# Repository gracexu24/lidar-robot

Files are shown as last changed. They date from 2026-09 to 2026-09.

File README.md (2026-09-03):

# Four-wheel ROS 2 LiDAR robot

ROS 2 Jazzy software for a Raspberry Pi 5, four STEP/DIR stepper drivers, an
MPU6050 IMU, and the Waveshare D500 kit (LDROBOT LD19 2D LiDAR). The package
supports physical hardware, keyboard driving, SLAM mapping, saved-map Nav2
navigation, and Gazebo Harmonic simulation.

1. [General project goal](#general-project-goal)
2. [File structure](#file-structure)
3. [Hardware list](#hardware-list)
4. [Project images](#project-images)
5. [Project features and decisions](#project-features-and-decisions)
6. [Issues and how we solved them](#issues-and-how-we-solved-them)
7. [Install](#install)
8. [Physical hardware setup and tests](#physical-hardware-setup-and-tests)
9. [Simulation](#simulation)
10. [Worklog](#worklog)

## General project goal

Build a small indoor/outdoor autonomous robot that can map a space, localize
in that map, and drive itself to a goal. The original product idea was a
cute food-delivery platform; later notes also listed outdoor jobs such as
trash collection, weed cutting, and GPS-guided travel. Those outdoor jobs
need extra sensors and tougher hardware, so this repository first proves the
core stack indoors:

- four-wheel skid-steer motion
- 2D LiDAR mapping with SLAM Toolbox
- saved-map navigation with Nav2
- optional IMU fusion for better short-term yaw
- a Gazebo simulation of the same ROS interfaces

The mechanical design is inspired by [TurtleBot3](https://www.turtlebot.com/turtlebot3/):
a simple mobile base, sensors on top, and replaceable skins rather than a
fixed enclosure. Early ideas included modular snap-fit tiles and
replaceable interior/exterior walls. The built robot uses a skateboard-style
3030 aluminum frame with 3D-printed motor mounts instead.

## File structure

```text
lidar-robot/
├── README.md
├── docs/
│   ├── cad/full-robot-assembly.stp  Fusion/STEP model of the built robot
│   └── images/                  Project photos and wiring figures
└── my_robot/                    ROS 2 Python package
    ├── package.xml              Package name, license, and dependencies
    ├── setup.py                 Installs nodes, launch, config, URDF, worlds
    ├── setup.cfg
    ├── resource/my_robot        ament package marker
    ├── config/
    │   ├── motors.yaml          GPIO pins and pulse-calibration numbers
    │   ├── mpu6050.yaml         I2C IMU driver settings
    │   ├── ekf.yaml             robot_localization fusion of wheels + IMU
    │   ├── slam.yaml            SLAM Toolbox mapping settings
    │   ├── nav2.yaml            AMCL, planners, costmaps, smoother
    │   └── gazebo_bridge.yaml   Gazebo ↔ ROS topic bridge
    ├── launch/
    │   ├── base.launch.py       Physical motors, LiDAR, optional IMU/EKF
    │   ├── mapping.launch.py    Physical base + SLAM Toolbox
    │   ├── navigation.launch.py Physical base + AMCL + Nav2
    │   ├── navigation_core.launch.py  Shared Nav2 servers
    │   ├── simulation.launch.py Gazebo robot, bridge, optional RViz
    │   ├── simulation_mapping.launch.py
    │   └── simulation_navigation.launch.py
    ├── my_robot/
    │   ├── base_controller.py   /cmd_vel → STEP rates + open-loop odom
    │   ├── stepper_hardware.py  Four GPIO pulse threads
    │   ├── mpu6050_driver.py    I2C IMU → /imu/data
    │   ├── lidar_reader.py      /scan connection diagnostics
    │   ├── manual_drive.py      Bounded front/back/left/right tests
    │   └── cmd_vel_watchdog.py  Simulation-only stale-command stop
    ├── urdf/robot.urdf          ROS frames and visual sizes
    ├── worlds/test_room.sdf     Gazebo room, robot, LiDAR, IMU
    ├── rviz/robot.rviz          Shared RViz layout
    └── test/                    Lint and mocked GPIO timing tests
```

How the main files work together:

- `base_controller.py` converts `/cmd_vel` (`linear.x`, `angular.z`) into left
  and right step rates, ramps those rates, stops if commands go stale, and
  publishes open-loop `/wheel/odom`.
- `stepper_hardware.py` owns the four STEP/DIR/RESET/SLEEP pins.
- `mpu6050_driver.py` publishes accelerometer and gyro data on `/imu/data`.
- `lidar_reader.py` reports closest-range and stale-scan warnings.
- `manual_drive.py` is the `ros2 run my_robot drive ...` test helper.
- `base.launch.py` starts the physical robot. Mapping and navigation launches
  include it, then add SLAM Toolbox or AMCL + Nav2.
- `navigation_core.launch.py` starts the shared Nav2 servers and remaps
  Jazzy's `/cmd_vel_smoothed` to `/cmd_vel`.
- Simulation launches use Gazebo instead of GPIO. They still speak
  `/cmd_vel`, `/odom`, `/scan`, `/imu/data`, and TF.

## Hardware list

CAD model: [docs/cad/full-robot-assembly.stp](docs/cad/full-robot-assembly.stp)
(Fusion 360 STEP export of the full robot assembly; open in Fusion 360, FreeCAD, or another STEP viewer.)

| Item | What we used | Notes |
| --- | --- | --- |
| Computer | Raspberry Pi 5 | Ubuntu 24.04 + ROS 2 Jazzy. An active fan was added after heat issues. |
| LiDAR | Waveshare D500 kit (LDROBOT LD19) | USB serial. Wiki: [D500 LiDAR Kit](https://www.waveshare.com/wiki/D500_LiDAR_Kit). |
| IMU | MPU6050 | I2C, default address `0x68` when AD0 is low. |
| Motors | 4 bipolar steppers, 1.8° / 200 steps per revolution | Early pick: [Olimex SM-42HB34F08AB](https://www.digikey.com/en/products/detail/olimex-ltd/SM-42HB34F08AB/21662229), 12 V, 1.33 A. Direct drive, no gearbox. |
| Drivers | 4 A4988 / A5984-style STEP/DIR boards | Current limit set near 1 A (`Vref` about 0.8 V on the boards we used). MS pins left unconnected, so the drivers stay in full-step mode. |
| Motor power | 12 V rechargeable pack, about 5.8 Ah | Sized for roughly an hour of four-motor current with margin. A 1 A wall supply was not enough for all four motors. |
| Pi power | Separate USB power bank / phone battery | Do not power motors from the Pi 5 V or 3.3 V pins. |
| Wheels | 4 in / about 10 cm diameter | Loaded radius in the URDF is 0.049 m. |
| Frame | 3030 aluminum extrusion | Replaced a planned one-piece carbon-fiber print. |
| Mounts | 3D-printed motor mounts and axle parts | Early notes used U-joints between 3 mm motor shafts and larger wheel shafts. |
| Caps | 100 µF electrolytic across each driver `VMOT`/`GND` | Limits supply spikes when stepping. |

Motor wiring color convention used during bring-up:

- `1A` black, `1B` green, `2A` red, `2B` blue

Split electrical system from the side-layout drawing: the phone battery feeds
the Pi, the 12 V pack feeds the motor drivers, and both grounds meet at the
drivers.

Default GPIO order is left-front, left-rear, right-front, right-rear (BCM
numbers, not physical header pins):

| Signal | LF | LR | RF | RR |
| --- | ---: | ---: | ---: | ---: |
| STEP | 14 | 23 | 17 | 5 |
| DIR | 15 | 24 | 27 | 6 |
| RESET | 4 | 25 | 22 | 26 |
| SLEEP | 12 | 7 | 16 | 1 |

`direction_inverted`: `[true, true, false, false]`

Change these in `my_robot/config/motors.yaml` if the physical wiring changes.

## Project images

These figures come from the project notebook. Photos of the assembled robot
are not in this repository yet.

Early modular-tile chassis sketch. This layout was later dropped for a
single skateboard-style frame.

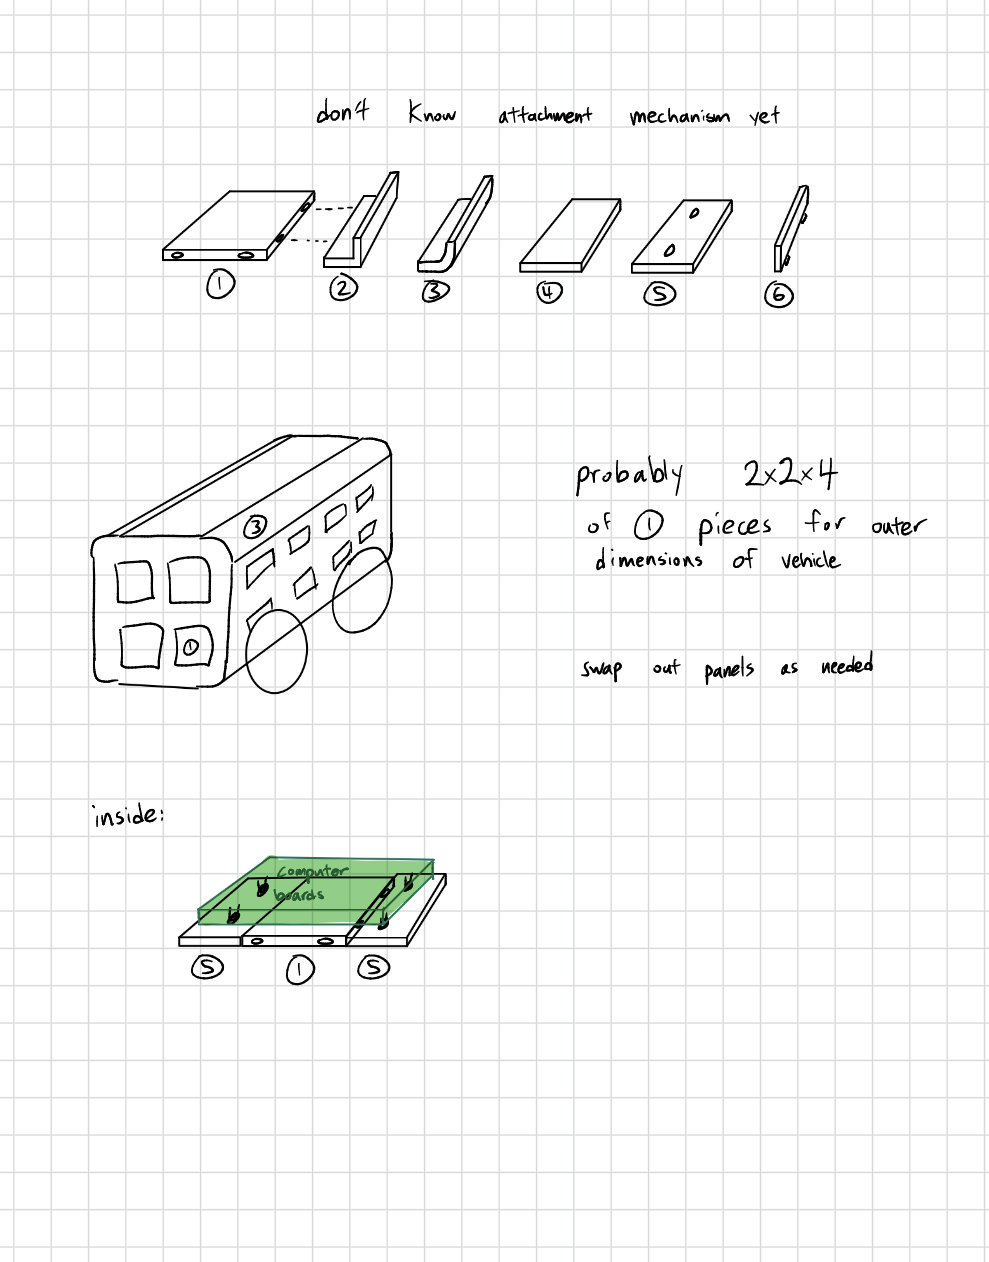
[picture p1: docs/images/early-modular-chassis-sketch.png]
Early modular chassis sketch


Motor, 4 in wheel, and U-joint notes, including shaft-strength estimates.

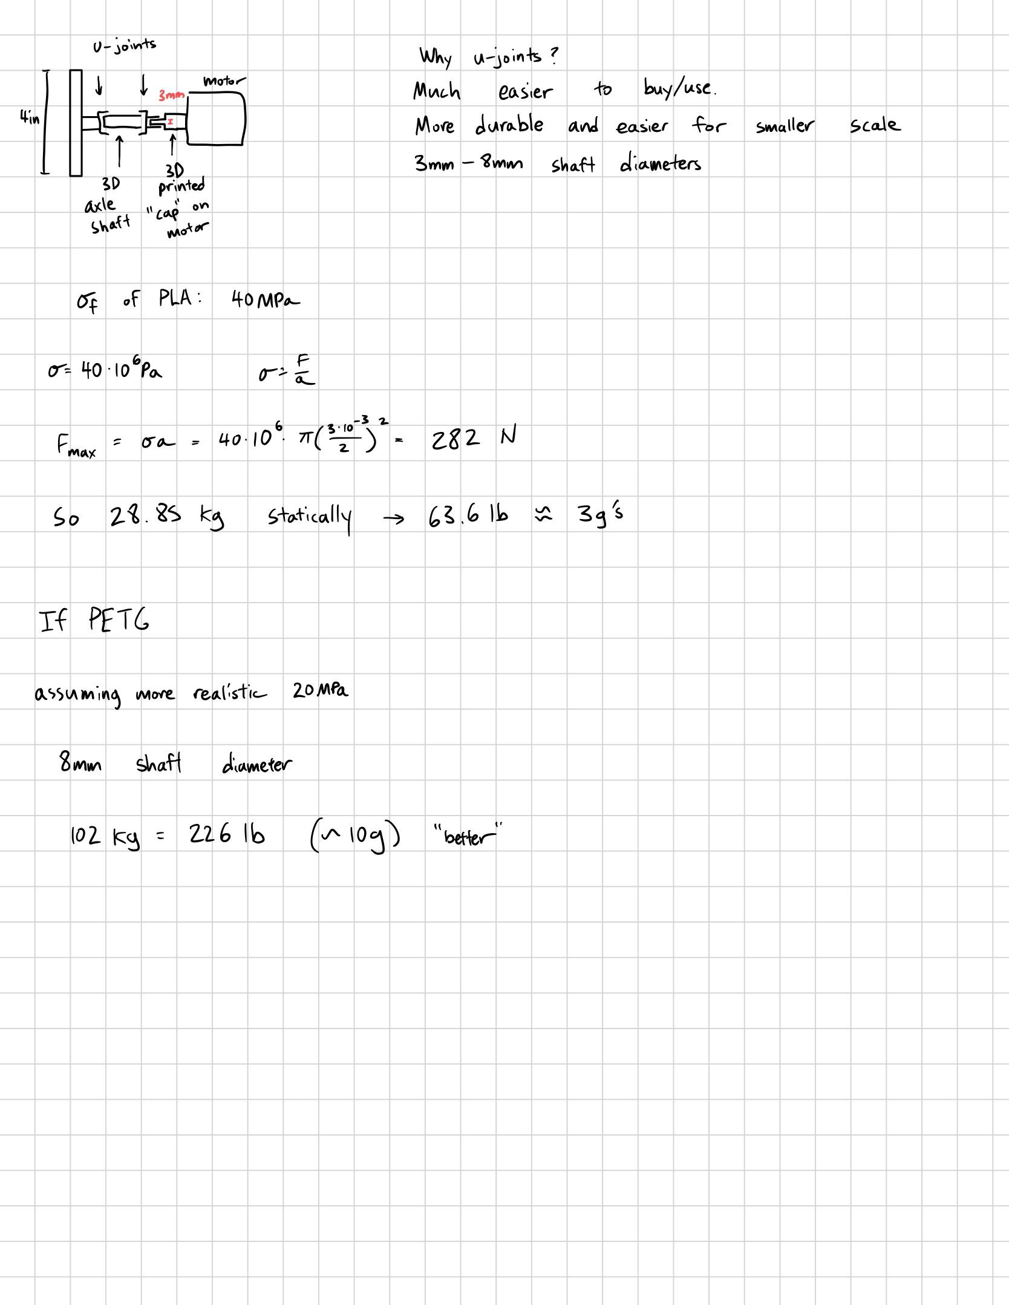
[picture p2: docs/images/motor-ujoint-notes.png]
Motor and U-joint notes


First 2D side-view layout. Red is signal, green is power. The LiDAR sits at
the front, the Pi and its battery in the middle, and the 12 V pack at the
rear.

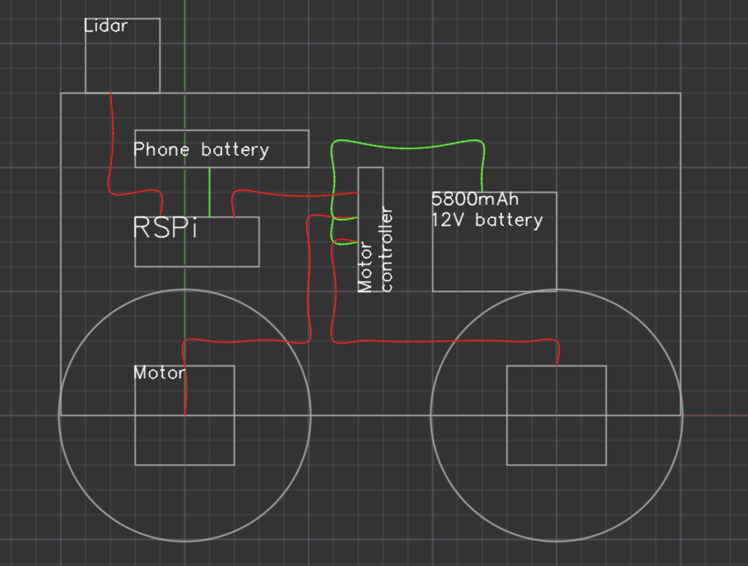
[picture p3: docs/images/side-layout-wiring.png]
Side layout and power/signal routing


A5984-style driver wiring used as the electrical reference: STEP/DIR from the
Pi, 100 µF on motor power, and a shared logic ground.

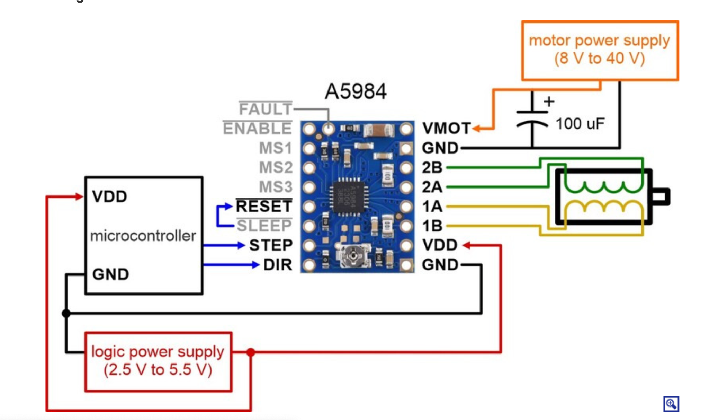
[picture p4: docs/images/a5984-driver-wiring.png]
A5984 stepper-driver wiring


## Project features and decisions

### Features that are in the repo

- Keyboard and bounded command-line driving (`front`, `back`, `left`, `right`)
- Open-loop wheel odometry from commanded stepper pulses
- D500 LiDAR scans on `/scan`
- Optional MPU6050 + EKF fusion
- Online SLAM mapping and map saving
- Saved-map Nav2 navigation
- Gazebo Harmonic simulation with the same high-level topics
- Collision-aware local planning with DWB; conservative speed limits for the Pi

### Mechanical decisions

- Four wheels instead of two, to keep the platform simple and stable. Notes
  assumed about 9 kg, 0.5 m/s, and 0.5 m/s² while sizing torque.
- Snap-fit 3 in tiles were dropped. 3D-printed latches were expected to creak,
  fit poorly, and be weak because printed plastic is not isotropic. Injection
  molding would have made that idea more realistic.
- A skateboard layout won: one strong flat frame, electronics on top, and a
  non-structural skin later.
- A single Markforged carbon-fiber frame was dropped after the print was
  estimated at more than 19 hours. 3030 extrusion plus printed motor mounts
  is easier to assemble and modify.
- Suspension was designed as a later add-on, not a first-version requirement.
- Camera support was planned and is not implemented yet.

### Electrical and software decisions

- Drive the steppers from the Pi GPIO with STEP/DIR pulses, not from an
  Arduino motor shield. One pulse is one full step (1.8°). Speed is the
  pulse frequency, not a PWM duty cycle.
- Leave driver MS pins unconnected. The A4988/A5984 internal pull-downs keep
  the chips in full-step mode, so the electrical step count is locked at 200
  pulses per motor revolution.
- Calibrate motion with `left_steps_per_meter`, `right_steps_per_meter`,
  `left_turn_steps_per_radian`, and `right_turn_steps_per_radian` instead of
  hiding error inside `wheel_radius` / `wheel_separation`.
- Use separate left and right turn coefficients because skid-steer left and
  right turns were not equal on the real floor.
- Keep IMU fusion optional. The MPU6050 has no magnetometer, so it helps
  short-term yaw rate and cannot provide absolute heading.
- Do not start Nav2 during mapping unless asked. The Pi was dropping scans
  and transforms when SLAM and Nav2 ran together.
- Build simulation around the same `/cmd_vel`, `/odom`, `/scan`, `/imu/data`,
  and TF contracts so mapping and Nav2 can be practiced without GPIO.

### Frames

- `base_footprint`: ground-level center used by Nav2 for planar collision
- `base_link`: chassis frame above the floor, normally at axle height
- `base_laser`: LiDAR scan origin; angle 0 is +X, forward
- `imu_link`: MPU6050 chip frame

ROS axes are +X forward, +Y left, and +Z up.

## Issues and how we solved them

| Problem | What we saw | Fix |
| --- | --- | --- |
| Wrong Ubuntu image | Pi stayed on a red light after a reflash | Ubuntu **24.04** is required for ROS 2 Jazzy binaries. Raspberry Pi OS is not a supported Jazzy platform. |
| Wall supply starved the motors | Four motors buzzed or refused to start together | Use the 12 V battery. A 1 A wall supply cannot feed four 1 A-class steppers. |
| Random wheels dead, stuck on, or buzzing | Motor 2 always on; motor 3 buzzed and did not turn | Rewired STEP/DIR/RESET/SLEEP, stopped RESET from being shorted, split shared jumper wires, and learned that RESET must stay high or STEP is ignored. |
| ENABLE vs RESET vs SLEEP confusion | Sleep seemed to work; RESET did not | RESET home-states the translator and ignores STEP until it is high. SLEEP cuts power and needs about 1 ms after wake before the next step. The code pulses RESET at start, holds it high, and uses SLEEP when a wheel is stopped. |
| GPIO pin conflicts | IMU needed I2C; some motor pins sit on UART/SPI | Moved motor pins to the table above. GPIO14/15 need the serial console off. GPIO7 is SPI CE1. GPIO1 is often reserved for HAT ID. |
| Vendor LiDAR package failed to build | Missing `pthread` in the given LDROBOT code | Build `ldlidar_stl_ros2` after ROS itself is installed, and keep the vendor package next to `my_robot` in `src`. |
| Printed parts did not fit | Assembly stopped | Measured the real robot, reprinted mounts, and put those sizes in the URDF. |
| Pi “battery” was not a battery | Logic power dropped | Separate USB power bank for the Pi; 12 V pack only for motors. |
| Distance math was wrong | 200 pulses turned the wheel once, but travel was about half the theoretical distance | Stopped treating `wheel_radius` as a software knob. Calibrate `steps_per_meter` from measured travel. Floor tests later landed near 707 / 699 steps/m. |
| Left and right turns disagreed | Left ~40° when 90° was requested; right needed a much larger coefficient | Separate `left_turn_steps_per_radian` and `right_turn_steps_per_radian`. Also check sagging hubs and drag before trusting the numbers. |
| Wheels sagged or fell off | Turns scrubbed; hubs walked off the shafts | Tape or glue hubs for tests; prefer moving arcs (`u`/`o`) over in-place `j`/`l` turns. |
| Motors stalled after raising speed | Buzz, missed steps, or no rotation | Raise `max_step_rate` and `max_step_acceleration` only after raised-wheel then floor tests. Current values are 500 steps/s and 300 steps/s²; older conservative limits were 75 and 100. |
| Pulse timing looked faster than commanded | 50 Hz controller woke every pulse thread even when the rate was unchanged | `set_rate()` now signals a thread only when the rate changes. A unit test covers that. |
| IMU did not start | `/imu/data` missing; mapping still fuzzy | Add the user to the `i2c` group, keep the robot still for gyro bias, and confirm `i2cdetect` shows `68`. One mapping run used a bad IMU init and only three wheels. |
| SLAM maps were fuzzy / scans dropped | Buffer warnings while printing debug | Turn `debug_logging` off while mapping. Do not start Nav2 during mapping unless needed. |
| Nav2 planned but the robot sat still | Controller rejected the path; wrong velocity topic | Jazzy smoother output is `/cmd_vel_smoothed`, not Humble's `/smoothed_cmd_vel`. `navigation_core.launch.py` remaps that to `/cmd_vel`. |
| Mapping plus Nav2 overloaded the Pi | Transform delays, `follow_path` timeouts | Mapping defaults to SLAM only. `bt_navigator` timeouts and AMCL transform tolerances were increased for the Pi. |
| Gazebo would not yaw | `/odom` said it turned; the body did not | SDF wheel friction was given a small lateral slip. That change is simulation-only. |
| Gazebo kept the last speed forever | Robot rolled after teleop stopped | `cmd_vel_watchdog.py` zeros velocity after 0.6 s. The physical controller already has a 0.5 s watchdog. |

Open limitations we did not fully remove:

- Odometry counts pulses sent to the drivers. It cannot see skipped steps or
  slip.
- Python on Linux is not hard real-time GPIO. Faster, cleaner motion would
  need a microcontroller generating STEP pulses.
- Outdoor GPS, camera, and suspension are still future work.
- Dependable navigation still wants wheel encoders.

## Install

Use 64-bit Ubuntu 24.04 and ROS 2 Jazzy.

Labels used below:

- **Once per machine**: run after a new OS install.
- **Pi only**: skip on a desktop that will only run Gazebo.
- **Desktop only**: skip on the Raspberry Pi.
- **Every new terminal**: ROS does not keep `source` across terminals.
- **After code changes**: launch, config, URDF, or Python edits.

### 1. ROS packages — once per machine

```bash
sudo apt update
sudo apt install -y ros-jazzy-desktop ros-jazzy-navigation2 \
  ros-jazzy-nav2-bringup ros-jazzy-slam-toolbox \
  ros-jazzy-robot-localization ros-jazzy-teleop-twist-keyboard \
  python3-rosdep
```

### 2. Raspberry Pi hardware packages — Pi only, once

```bash
sudo apt install -y python3-gpiozero python3-lgpio python3-smbus2 i2c-tools
```

### 3. Gazebo packages — desktop only, once

```bash
sudo apt install -y ros-jazzy-ros-gz
```

### 4. rosdep — once per machine

If it says rosdep is already initialized, continue with `rosdep update`.

```bash
sudo rosdep init
rosdep update
```

### 5. Workspace and source — once per machine

```bash
mkdir -p ~/ros2_ws/src
cd ~/ros2_ws/src
git clone https://github.com/gracexu24/lidar-robot.git
git clone https://github.com/ldrobotSensorTeam/ldlidar_stl_ros2.git
```

Later updates on the Pi are `git pull` inside this repo, then rebuild.

### 6. Dependencies and first build — once, then after new dependencies

```bash
cd ~/ros2_ws
source /opt/ros/jazzy/setup.bash
rosdep install --from-paths src --ignore-src -r -y
colcon build --symlink-install
source ~/ros2_ws/install/setup.bash
```

`source /opt/ros/jazzy/setup.bash` must run before `rosdep install` and
`colcon build`. The vendor LiDAR package expects ROS to already be installed.

### 7. Every new terminal

```bash
source /opt/ros/jazzy/setup.bash
source ~/ros2_ws/install/setup.bash
```

Confirm the package is visible:

```bash
ros2 pkg prefix my_robot
```

### 8. After changing package files

```bash
cd ~/ros2_ws
source /opt/ros/jazzy/setup.bash
colcon build --symlink-install --packages-select my_robot
source ~/ros2_ws/install/setup.bash
```

### 9. Package tests — optional, after code changes

```bash
cd ~/ros2_ws
source /opt/ros/jazzy/setup.bash
colcon test --packages-select my_robot
colcon test-result --verbose
```

The tests include lint checks and mocked motor sleep/reset/timing checks.
They do not move hardware.

### 10. One-time Pi permissions

Serial (LiDAR). Log out or reboot after the group change:

```bash
sudo usermod -aG dialout "$USER"
groups
```

I2C (IMU):

```bash
sudo usermod -aG i2c "$USER"
```

Enable I2C in `/boot/firmware/config.txt` if `/dev/i2c-1` is missing
(`dtparam=i2c_arm=on`), then reboot.

## Physical hardware setup and tests

Save work before unplugging the Pi. Unplug motor power before moving wires.

The Raspberry Pi GPIO pins must connect to stepper-driver logic inputs, not
directly to motors. Use one correctly sized driver per motor, an external
motor power supply, current limiting, and a common ground between the
supply, drivers, and Pi. Never power motors from a Pi 5 V or 3.3 V pin.

Raise the wheels for initial tests and keep a physical emergency motor-power
disconnect within reach.

GPIO7 is SPI CE1 and is unavailable while SPI is enabled. Either choose
another GPIO and move that SLEEP wire, or disable SPI in
`/boot/firmware/config.txt` if no other device uses it. GPIO14 and GPIO15
are UART pins, so the serial console must not use them.

The code assumes active-low RESET and SLEEP, as used by A4988-style drivers.
It pulses RESET during initialization, leaves RESET high, and pulls SLEEP
low when a wheel is stopped. Verify these levels against the exact driver
datasheet.

Driver current limit used on this robot: about 1 A, `Vref` about 0.8 V.
Set that on each board before long runs. See
[this current-limit walkthrough](https://youtu.be/89BHS9hfSUk?si=mE6hSFoFv12Aey9d)
if the pot location is unclear.

### Shared ROS commands

These commands are used by both the physical robot and simulation.

#### Keyboard control

A robot or simulation launch must already be running. In a separate sourced
terminal:

```bash
ros2 run teleop_twist_keyboard teleop_twist_keyboard \
  --ros-args --remap cmd_vel:=/cmd_vel
```

Useful keys:

- `i`: forward
- `,`: reverse
- `j`: turn left
- `l`: turn right
- `u` and `o`: move forward in left and right arcs
- `k`: stop
- `q` and `z`: increase and decrease all speeds
- `w` and `x`: increase and decrease linear speed
- `e` and `c`: increase and decrease angular speed
- `Ctrl+C`: exit

Prefer moving arcs instead of stationary turns when possible. Keyboard `u`
and `o` combine forward motion with turning, reducing tire scrub and stress
on the wheel hubs.

The physical motor controller has a 0.5-second watchdog, so hold or repeat a
movement key. Press `k` before leaving the keyboard terminal.

#### RViz setup

Simulation launches already start RViz with `rviz/robot.rviz`. That config
uses Fixed Frame `map` and adds the saved map, costmaps, laser scan, robot
model, TF, and the Navigation 2 panel.

Start RViz manually when a launch does not start it:

```bash
rviz2 -d "$(ros2 pkg prefix my_robot)/share/my_robot/rviz/robot.rviz"
```

For basic driving without SLAM or Nav2, use `odom` as the Fixed Frame. For
mapping and navigation, keep `map`. If a Map display shows nothing, set its
topic durability to Transient Local; `/map` is published once, not
continuously.

When using SSH, run RViz on another ROS 2 Jazzy computer on the same ROS
domain, use X11 forwarding, or use Foxglove.

#### Save the active map

Keep the mapping launch running. In another sourced terminal, choose a
filename without an extension and run:

```bash
MAP_NAME=${MAP_NAME:-$HOME/maps/home}
mkdir -p "$(dirname "$MAP_NAME")"
ros2 run nav2_map_server map_saver_cli -f "$MAP_NAME"
ls -l "$MAP_NAME.yaml" "$MAP_NAME.pgm"
```

Both the YAML and image file must exist before stopping mapping. Change
`MAP_NAME` to `$HOME/maps/sim_home` when saving a simulation map.

### Configure LiDAR serial access

Connect the D500 USB adapter and find its stable path:

```bash
ls -l /dev/serial/by-id/
```

Use the `/dev/serial/by-id/...` path in launch commands. `/dev/ttyUSB0` is
used below for brevity. Do not use broad `chmod 666` or `chmod 777`
permissions as a permanent solution.

### Motor connection test

Raise all wheels and start only the physical motor controller:

```bash
ros2 launch my_robot base.launch.py \
  start_motors:=true start_lidar:=false use_imu:=false \
  debug_logging:=true
```

In another sourced terminal, issue one bounded command at a time:

```bash
ros2 run my_robot drive front --duration 1 --speed 0.05
ros2 run my_robot drive back --duration 1 --speed 0.05
ros2 run my_robot drive left --duration 1 --turn-speed 0.4
ros2 run my_robot drive right --duration 1 --turn-speed 0.4
```

The debug output reports GPIO initialization, target and actual pulse rates,
pulse counts, wake/sleep changes, and watchdog stops. Pulse counts prove
that software generated pulses; without encoders they do not prove that a
motor physically moved.

### Keyboard-only motor movement

Raise-test all wheels first. Terminal 1 starts the motor controller without
the LiDAR or IMU:

```bash
ros2 launch my_robot base.launch.py \
  start_motors:=true start_lidar:=false use_imu:=false \
  debug_logging:=true
```

In Terminal 2, run the command under **Keyboard control**.

### IMU connection test

The I2C scan must show address `68`, or `69` when AD0 is tied high:

```bash
ls -l /dev/i2c-1
i2cdetect -y 1
```

Keep the robot still and start only the MPU6050 node:

```bash
ros2 run my_robot mpu6050_driver --ros-args \
  --params-file "$(ros2 pkg prefix my_robot)/share/my_robot/config/mpu6050.yaml" \
  -p debug_logging:=true
```

In another sourced terminal:

```bash
timeout 5s ros2 topic hz /imu/data
ros2 topic echo /imu/data --once
```

The data rate should be near 50 Hz. At rest, angular velocity should be near
zero and total acceleration near 9.8 m/s². Keep the robot still for the
first approximately 2.5 seconds while gyro bias is measured.

### LiDAR connection test

Start only the LiDAR:

```bash
ros2 launch my_robot base.launch.py \
  start_motors:=false start_lidar:=true use_imu:=false \
  lidar_port:=/dev/ttyUSB0 debug_logging:=true
```

In another sourced terminal:

```bash
ros2 topic info /scan --verbose
timeout 5s ros2 topic hz /scan
ros2 topic echo /scan --once
```

The expected rate is about 10 Hz. A few `nan` values are normal when no
valid reflection is returned. Debug output reports the closest valid
distance and warns when the scan stream is missing or stale.

In RViz, set Fixed Frame to `base_laser`, add `/scan` as a LaserScan, and
move an object in front of the sensor.

### Values to measure and tune

Use metres, radians, seconds, kilograms, and SI-derived units throughout the
configuration. Define `base_link` at the robot's rotation center: halfway
between the front and rear axles, on the left-to-right centerline, at axle
height. `base_footprint` is the point directly below it on the floor.

Record these physical measurements before calibration:

- loaded wheel radius: axle center to floor with the robot at operating weight
- left-to-right wheel separation: center of left tread to center of right tread
- wheelbase: front axle center to rear axle center
- overall body length, width, and height, including parts that can collide
- front, rear, left, and right extents measured from `base_link`
- floor-to-axle height
- robot total mass and approximate center of mass, if Gazebo should be realistic
- LiDAR sensing-center position and orientation relative to `base_link`
- IMU chip-center position and board orientation relative to `base_link`

Enter or tune the following values.

#### `my_robot/config/motors.yaml`

- `step_pins`, `dir_pins`, `reset_pins`, `sleep_pins`: actual BCM GPIO wiring
  in LF, LR, RF, RR order
- `direction_inverted`: one Boolean per wheel; tune with the wheels raised
- `left_steps_per_meter`: calibrated average left-side pulses per metre
- `right_steps_per_meter`: calibrated average right-side pulses per metre
- `left_turn_steps_per_radian`: average pulses for one radian of left rotation
- `right_turn_steps_per_radian`: average pulses for one radian of right rotation
- `max_step_rate`: highest reliable pulse rate in steps/s without missed steps
- `max_step_acceleration`: highest reliable ramp in steps/s² without stalling
- `command_timeout`: safety stop delay in seconds; normally leave at 0.5

The current controller sends one rate to both left wheels and another to both
right wheels. Physical wheel radius and separation remain real dimensions in
the URDF and Gazebo model; motor conversion uses the directly measured pulse
coefficients above.

#### `my_robot/urdf/robot.urdf`

- body box `size`: measured length, width, and height in metres
- body visual `origin xyz`: body-box center relative to `base_link`
- `base_joint` Z: floor-to-`base_link` height, normally the loaded wheel radius
- `laser_joint xyz`: `base_link` to the LiDAR rotating/sensing center in metres
- `laser_joint rpy`: LiDAR roll, pitch, and yaw in radians
- `imu_joint xyz`: `base_link` to the center of the MPU6050 chip in metres
- `imu_joint rpy`: rotation needed to align IMU axes with the ROS robot axes

Common angles are 90° = 1.5708 rad and 180° = 3.1416 rad. Sensor positions
must be measured to the sensing center, not to an enclosure edge.

#### `my_robot/config/mpu6050.yaml`

- `i2c_bus`: bus reported by the system, normally `1`
- `i2c_address`: `0x68` or `0x69`, as reported by `i2cdetect`
- `gyro_stddev`: stationary angular-velocity standard deviation in rad/s
- `accel_stddev`: stationary linear-acceleration standard deviation in m/s²
- `publish_rate`: measured sustainable data rate; normally leave at 50 Hz
- `calibration_samples`: increase for a steadier bias estimate if startup time
  is acceptable; keep the robot still for all samples

The `frame_id` must remain the same as the URDF IMU link unless both are
renamed together.

#### `my_robot/config/nav2.yaml`

- robot collision shape in both local and global costmaps: use either
  `robot_radius` or a `footprint`, but not both
- `robot_radius`: center to the furthest collidable point plus a small margin
- rectangular `footprint`: ordered `[x, y]` corners measured from
  `base_footprint`, including wheels, bumpers, and sensor mounts
- `footprint_padding`: additional collision margin, typically 0.01–0.03 m
- `inflation_radius`: desired navigation clearance around obstacles
- `obstacle_max_range`: maximum range at which LiDAR returns are reliably marked
- `raytrace_max_range`: reliable clearing range, slightly greater than the
  obstacle range but not beyond useful LiDAR data
- `max_vel_x` and `max_vel_theta`: safe measured linear and angular speeds
- `acc_lim_x`, `decel_lim_x`, `acc_lim_theta`, `decel_lim_theta`: acceleration
  limits that do not cause skipped steps or tipping
- velocity-smoother limits: keep them consistent with the controller limits
- goal tolerances and progress timeout: tune only after odometry is calibrated

For a centered rectangular robot, the minimum enclosing radius is:

```text
robot_radius = sqrt((length / 2)² + (width / 2)²) + safety margin
```

A more accurate asymmetric footprint uses the measured extents:

```yaml
footprint: "[[front, left], [front, -right], [-rear, -right], [-rear, left]]"
footprint_padding: 0.02
```

Replace `front`, `rear`, `left`, and `right` with distances in metres, and
use the same footprint in both costmaps.

#### `my_robot/config/slam.yaml`

- `max_laser_range`: maximum distance that produces dependable measurements,
  not merely the advertised maximum
- `resolution`: map cell size in metres; 0.05 m is a normal starting point
- minimum travel distance and heading: tune only if maps update too often or
  fail to update during deliberate motion

#### `my_robot/worlds/test_room.sdf`

These values affect only Gazebo. Copy calibrated real dimensions when the
simulation should match the physical robot:

- body collision and visual length, width, height, and center
- wheel X/Y positions, radius, width, mass, and inertia
- `wheel_separation` and `wheel_radius` in the DiffDrive plugin
- robot mass, center of mass, and inertia estimates
- simulated LiDAR and IMU poses
- LiDAR minimum/maximum range, sample count, and update rate

The URDF and SDF are separate models; changing one does not update the other.
The current SDF is synchronized to the measured 0.24 × 0.16 × 0.04 m body,
0.049 m wheel radius, 0.03 m wheel width, 0.165 m wheel separation, and
current LiDAR and IMU transforms. It still assumes a 0.22 m wheelbase, 8 kg
base mass, and 0.3 kg per wheel until those values are measured.

### Calibration procedure

1. Verify all GPIO assignments against the physical wiring.
2. Raise the wheels and tune `direction_inverted`.
3. Calculate initial steps/metre, then measure left and right travel.
4. Find conservative step-rate and acceleration limits.
5. Calibrate straight distance, then steps/radian for turns.
6. Enter body and sensor measurements in the URDF and Nav2 costmaps.
7. Validate IMU axes and noise values.
8. Copy the final geometry into the Gazebo SDF if simulation should match.

Calculate an initial translation estimate from the electrical and mechanical
configuration:

```text
steps_per_wheel_revolution =
    motor full steps/revolution × microstep setting × gearbox ratio

initial steps_per_meter =
    steps_per_wheel_revolution ÷ (2π × loaded wheel radius)
```

The A4988 MS1, MS2, and MS3 inputs have internal pull-down resistors. When
all three pins are unconnected, the driver uses full-step mode. Therefore a
1.8° motor requires 200 STEP pulses per motor revolution. With direct drive,
that is also 200 pulses per wheel revolution. A gearbox would multiply this
value by its reduction ratio.

Use this result as the initial value for both `left_steps_per_meter` and
`right_steps_per_meter`. The controller changes STEP frequency to change
speed:

```text
left frequency = requested translation × left_steps_per_meter
                 - requested rotation × direction_turn_steps_per_radian

right frequency = requested translation × right_steps_per_meter
                  + requested rotation × direction_turn_steps_per_radian
```

With a 0.049 m wheel radius and 200 steps/revolution, the theoretical
starting value is about 650 steps/m. Use the configured left and right
values when calculating the requested pulse rates.

#### Correct movement directions

Raise all wheels and run the short front, back, left, and right commands
from the motor test:

- `front`: all four wheel contact surfaces must move toward the robot's rear,
  which propels the robot forward when placed on the floor
- `back`: all four wheels must reverse
- `left`: left wheels reverse while right wheels move forward
- `right`: right wheels reverse while left wheels move forward

If one wheel is reversed, toggle only its matching `direction_inverted`
entry. If an entire side behaves incorrectly, verify LF/LR/RF/RR GPIO
ordering before changing calibration. Pulse calibration changes distance and
angle, not GPIO direction.

#### Calibrate forward and backward distance

Use a flat, high-traction surface at operating weight. Mark the start point
and run:

```bash
ros2 run my_robot drive front --duration 10 --speed 0.10
```

The expected distance is speed × duration, or 1.0 m for this command.
Measure from the same physical point before and after movement. Calibrate
each side from generated pulse counts and measured distance:

```text
steps_per_meter = generated side pulse count ÷ measured distance
```

For a simple whole-robot correction when individual pulse counts were not
recorded:

```text
new side steps_per_meter =
    old side steps_per_meter × expected distance ÷ measured distance
```

Repeat forward at least three times and use the average measured distance.
Then repeat backward. If forward and backward differ substantially, inspect
driver current limits, loose wheels, backlash, floor slip, battery voltage,
and missed steps; fixed coefficients cannot correct a direction-dependent
mechanical error.

If the robot consistently curves while all four directions are correct, do
not change turn calibration first. Correct left/right steps-per-metre values
only after checking unequal wheel diameters, binding, driver current, motor
skipping, weight distribution, and traction. There are side-specific
coefficients, but no individual-wheel coefficients or encoders.

Measured bring-up points from the notebook:

- 4 s at 0.25 m/s should travel 1.0 m
- first floor set: 1.13 m, 1.23 m, 1.18 m
- after raising `max_step_rate` and retuning: 0.93 m, 0.93 m, then a
  consistent straight line
- wheels were taped during some of those runs

#### Calibrate turns

After straight distance is accurate, mark the robot's initial heading and
request a slow 180° left turn:

```bash
ros2 run my_robot drive left --duration 15.708 --turn-speed 0.20
```

A quicker check used during bring-up was:

```bash
ros2 run my_robot drive left --duration 3.142 --turn-speed 0.5
```

That command requested about 90° and produced about 40° before the left
coefficient was increased.

Measure the actual angle. Apply the correction separately to
`left_turn_steps_per_radian` or `right_turn_steps_per_radian`:

```text
new direction_turn_steps_per_radian =
    old direction_turn_steps_per_radian × expected angle ÷ measured angle
```

It can also be calculated directly when pulse totals are available:

```text
direction_turn_steps_per_radian =
    average absolute side pulse count ÷ measured angle in radians
```

Repeat each direction several times and average its results. Calibrate on
the same floor used for navigation because four-wheel skid-steer turning
depends strongly on tire scrub and traction. If the directional values
differ greatly, correct mechanical drag, loose hubs, motor current, wheel
size, or weight balance; direction-specific calibration must not hide an
unstable fault.

#### Tune rate and acceleration

Begin at low speed with the wheels raised, then test on the floor at
operating weight. Reduce `max_step_rate` when motors buzz, stop rotating, or
lose steps at steady speed. Reduce `max_step_acceleration` when they lose
steps while starting, stopping, or reversing. Set conservative limits below
the first failure point, then repeat the straight and turn calibration
because missed steps invalidate those measurements.

### Map with the physical robot

Terminal 1 starts the robot and SLAM Toolbox. Nav2 is disabled during
manual mapping by default to reduce CPU load and transform delays:

```bash
ros2 launch my_robot mapping.launch.py \
  lidar_port:=/dev/ttyUSB0 use_imu:=false debug_logging:=false
```

Set `start_nav2:=true` only when Nav2 servers are specifically needed while
mapping.

Terminal 2 runs RViz using the shared RViz setup with Fixed Frame `map`.
Terminal 3 runs the shared keyboard-control command.

Drive slowly along boundaries, avoid rapid turns, and revisit the starting
area to create loop closures. Verify that walls remain sharp and aligned. In
Terminal 4, follow **Save the active map** while mapping remains running.

Add `use_imu:=true` only after the IMU test succeeds. The MPU6050 improves
short-term turn estimates but has no magnetometer and cannot eliminate
long-term yaw drift.

Notebook mapping runs:

- Map 1: usable but noisy; a wheel came off
- Map 2: IMU enabled and slower speeds; IMU had not initialized
- Map 3: different IMU rate and only three wheels; turns still smeared the map

### Navigate on a physical saved map

Stop mapping, then start saved-map navigation in Terminal 1:

```bash
ros2 launch my_robot navigation.launch.py \
  map:=$HOME/maps/home.yaml \
  lidar_port:=/dev/ttyUSB0 use_imu:=false debug_logging:=true
```

Terminal 2 runs RViz with Fixed Frame `map`. Use **2D Pose Estimate** to set
the robot's measured starting position and heading. Send a short
unobstructed **Nav2 Goal**, then increase the distance after verifying
localization, obstacle detection, stopping, and recovery behavior.

Nav2 can handle some moving obstacles, but this platform is not a safety
system. It should not be trusted around people or fragile objects without a
person ready to cut motor power.

## Simulation

Simulation and hardware use the same high-level ROS 2 interfaces:

- `/cmd_vel` carries movement commands
- `/odom` reports robot motion
- `/scan` provides LiDAR measurements
- `/imu/data` provides IMU measurements
- the TF tree describes the robot frames
- SLAM Toolbox, Nav2, and their configuration files are shared

The low-level implementations are different. On hardware, `base_controller.py`
creates STEP/DIR pulses, the LDROBOT driver publishes real scans, and
`mpu6050_driver.py` publishes real IMU data. In Gazebo, a DiffDrive plugin
replaces GPIO motors, simulated sensors replace the D500 and MPU6050, and
`cmd_vel_watchdog.py` stops the model about 0.6 s after `/cmd_vel` goes
stale.

Simulation therefore tests mapping, localization, navigation, transforms,
and topic connections. It does not test GPIO timing, wiring, driver
current, missed steps, tire scrub, USB LiDAR enumeration, or MPU6050 I2C.
Calibrate the physical drivetrain even when Gazebo looks correct.

### Files that exist only for Gazebo

- `worlds/test_room.sdf`: room, obstacles, four-wheel robot, GPU LiDAR, IMU.
  Wheel cylinders are rotated −90°, joint axes are in the model frame, and
  wheel friction has a small lateral slip so skid-steer can yaw.
- `config/gazebo_bridge.yaml`: clock, commands, odometry, TF, scans, IMU.
  Gazebo listens on `/cmd_vel_safe`.
- `my_robot/cmd_vel_watchdog.py` and `launch/simulation.launch.py`: stop
  Gazebo when `/cmd_vel` is stale.
- `launch/simulation_navigation.launch.py`: sets `set_initial_pose:=true`
  because the simulated robot always starts at the world origin.

Do not copy SDF wheel friction, Gazebo axis fixes, or the simulation
watchdog onto the Raspberry Pi.

### Shared changes that also apply on hardware

- `launch/navigation_core.launch.py` remaps `/cmd_vel_smoothed` to
  `/cmd_vel`. The old Humble name left Nav2 planning while the robot sat
  still.
- `config/nav2.yaml`: AMCL `transform_tolerance` 1.0 s, global costmap
  `initial_transform_timeout` 60 s, controller frequency 10 Hz, and a
  larger DWB transform tolerance.
- `launch/navigation.launch.py`: optional `set_initial_pose` (default
  `false` on hardware). On the Pi, still use **2D Pose Estimate**.
- `rviz/robot.rviz`: the same layout can visualize the physical robot.

`nav2.yaml` speed limits stay conservative (`max_vel_x` 0.10 m/s) for both
targets. Raise them only after the physical wheels are calibrated.

The robot is embedded in `worlds/test_room.sdf`; it is not spawned from the
URDF. `urdf/robot.urdf` still supplies the static ROS transform tree used by
RViz and Nav2.

### Bring-up

Use a desktop with Gazebo Harmonic. Source the workspace in every terminal.
Run only one Gazebo instance. After changing launch, config, URDF, SDF, or
RViz files, rebuild and source again.

Typical sequence:

1. Drive with `ros2 launch my_robot simulation.launch.py start_rviz:=true`
   and keyboard teleop. In this mode only, set RViz Fixed Frame to `odom`.
2. Map with `ros2 launch my_robot simulation_mapping.launch.py start_rviz:=true`,
   drive the walls slowly, then save `$HOME/maps/sim_home`.
3. Stop mapping. Navigate with
   `ros2 launch my_robot simulation_navigation.launch.py map:=$HOME/maps/sim_home.yaml start_rviz:=true`.
   Wait until the log says `Managed nodes are active`, then send a short
   Nav2 Goal.

### Basic simulation and keyboard movement

```bash
ros2 launch my_robot simulation.launch.py start_rviz:=true
```

In a second sourced terminal, run **Keyboard control**. In RViz, use Fixed
Frame `odom`.

Validate the simulated interfaces:

```bash
ros2 topic echo /clock --once
timeout 5s ros2 topic hz /scan
timeout 5s ros2 topic hz /odom
timeout 5s ros2 topic hz /imu/data
ros2 run tf2_ros tf2_echo odom base_footprint
```

Without a display:

```bash
ros2 launch my_robot simulation.launch.py headless:=true
```

### Create a map in simulation

Stop any existing Gazebo launch first.

```bash
ros2 launch my_robot simulation_mapping.launch.py start_rviz:=true
```

Drive the complete room and revisit the start. In RViz, use Fixed Frame
`map`. Save the map with:

```bash
export MAP_NAME=$HOME/maps/sim_home
```

then follow **Save the active map**. Stop mapping only after both
`sim_home.yaml` and `sim_home.pgm` exist.

### Navigate on a simulated saved map

```bash
ros2 launch my_robot simulation_navigation.launch.py \
  map:=$HOME/maps/sim_home.yaml start_rviz:=true
```

Simulation navigation seeds AMCL at the Gazebo origin. Confirm alignment;
use **2D Pose Estimate** only if the robot is offset. Then send a short
**Nav2 Goal**. Verify costmaps, `/cmd_vel`, stopping, and recovery.

If AMCL logs `Please set the initial pose` or Nav2 says `Action server is
inactive`, AMCL has not published `map` yet. Rebuild, source, and restart
the launch. On the physical robot, set **2D Pose Estimate** within about
one minute of launch.

### What was verified in simulation

- Straight forward and reverse motion, then in-place left and right turns
- Simulated `/scan`, `/odom`, `/imu/data`, and `/clock`
- SLAM Toolbox building `/map` while driving the test room
- AMCL localizing on a saved map after an origin pose is available
- Nav2 accepting a goal and sending velocity through the smoother into Gazebo

## Worklog

### 8 June

Preliminary design and a first outdoor-use discussion. Product ideas:
food delivery, trash collection, weed cutting, GPS-guided travel. Outdoor
work would need more than LiDAR and a tougher drivetrain.

### 19 June

Hardware purchased. Motor sizing used a 9 kg, 0.5 m/s, 0.5 m/s² estimate
and 2 in wheels, then moved toward larger 4 in wheels. Driver options
compared Adafruit/Pololu I2C boards against cheaper STEP/DIR boards with a
current pot.

### 20 June

Raspberry Pi setup: Ubuntu on the SD card, a Pi battery, and D500 LiDAR
research from the Waveshare wiki. Next software work was ROS, Git, and a
first `/scan` bring-up.

### 22 June

Soldered motor-controller boards, added 100 µF capacitors, set driver
current limits, checked the 12 V supply wattage, and wrote the first STEP
pulse scripts.

### 9 July

Added an active Pi fan. First pinout: GPIO 17 STEP, 27 DIR, 22 RESET, with
coil colors black/green/red/blue. Confirmed the drivers use STEP/DIR, not
PWM. A ten-step `gpiozero` script proved that RESET must be high before
pulses do anything.

### 12 July

Dropped the snap-fit tile frame because of print strength, latch fit, and
weight. Switched to a skateboard-style single frame with a cosmetic skin.
Suspension stayed low priority. Documented that one STEP pulse is 1.8°, and
the delay between pulses is speed.

### 24 July

Software plan: Gazebo first, then the repo, then electronics. Required
code: motor interface, odometry, URDF, configuration. Required tests:
LiDAR in ROS, wheels in ROS, shape calibration, SLAM, autonomous motion.
Workflow: SSH into the Pi from Cursor, push, pull on the Pi.

### 14 August

Body-on-frame with 3030 aluminum extrusion after the Markforged carbon
frame print was more than 19 hours. Bought 400 mm 3030 and sliding M5 nuts;
the extrusion was shorter than the first CAD, so the model had to change.
First 2D side-view layout drawn, with a note that the stack might be top
heavy.

### 18 August

Full wiring diagram. Current limit set to about 1 A / 0.8 V `Vref`. Local
Python venv used `gpiozero` for the first multi-motor scripts. Repo split
into LiDAR test, motor test, and mechanical fitting.

### 20 August

Multi-motor debug. Learned RESET, ENABLE, and SLEEP from the A5984 notes.
Issues: motor 2 stuck on, motor 1 buzzed after stop, motor 3 buzzed and did
not move, motor 4 worked only after rewiring. Fixes were wiring, RESET
shorts, and split jumpers. The 1 A wall supply could not run four motors;
the battery could. Recorded 200 pulses = 1 revolution and 10 cm wheel
diameter. First travel test: one wheel revolution did not travel the
expected distance. Direction bits that produced forward motion:

```text
Dir1 on, Dir2 off, Dir3 on, Dir4 off
```

### 24 August

Pi showed a red power light; a reflash failed until Ubuntu 24.04 was used.
Reconnected GitHub SSH. Started IMU work and had to move pins for I2C.
Vendor LiDAR code was missing `pthread`. GPIO map locked to the current
LF/LR/RF/RR table. Printed parts did not fit and needed a reprint. The Pi
power pack was not actually a battery.

### 27 August

Robot measurements taken. Test plan: update sizes, map with LiDAR, drive
manually, save a map, try autonomous. First motor trial: one wheel dead,
then two; assumed one driver had failed. LiDAR scan looked sparse. Notes
on `base_footprint` / `base_link` / `base_laser` written. Safety reminder:
save before unplugging, unplug power before moving wires.

### 29 August

Replacement motor driver worked. Right turns were worse than left. Wheels
sagged. First numeric calibration:

```bash
ros2 run my_robot drive front --duration 4 --speed 0.25
```

Measured 1.13 m, 1.23 m, and 1.18 m instead of 1.0 m. Wheels taped for
repeatability. Realized the code cannot change electrical microstepping
because the MS pins were never wired; speed has to come from step
frequency. Ubuntu remote-desktop access set up for the Pi.

### 31 August

Second calibration after raising max speed. The same 4 s / 0.25 m/s
command traveled 0.93 m twice and held a straight line. Left turn at
3.142 s / 0.5 rad/s produced about 40°. IMU vs no-IMU mapping compared.
Map 1 was acceptable until a wheel came off. Map 2 used IMU and slower
speeds, but the IMU had not initialized. Map 3 used a different IMU rate
and three wheels; turns still ruined the map. Nav2 planned a path but the
controller was subscribed to the wrong velocity topic. Debug printing was
starving the SLAM scan buffer. Batteries were running down during tests.

### 1 September

Floor tests replaced the theoretical 650 steps/m values with 707.0 and
698.9. Unequal in-place turns produced separate left/right radian
coefficients (170.0 and 482.4). Rate/acceleration limits were raised from
the original 75 / 100 comments to 500 / 300. IMU publish rate stayed at
50 Hz and the EKF at 20 Hz. Mapping no longer starts Nav2 by default.
Nav2's velocity smoother remap was corrected from `smoothed_cmd_vel` to
`cmd_vel_smoothed`, controller frequency set to 10 Hz, and `bt_navigator`
timeouts increased so the Pi can acknowledge `follow_path`. Node shutdown
now uses `rclpy.try_shutdown()` so Ctrl+C does not look like a crash.
`set_rate()` no longer wakes pulse threads when the rate is unchanged.

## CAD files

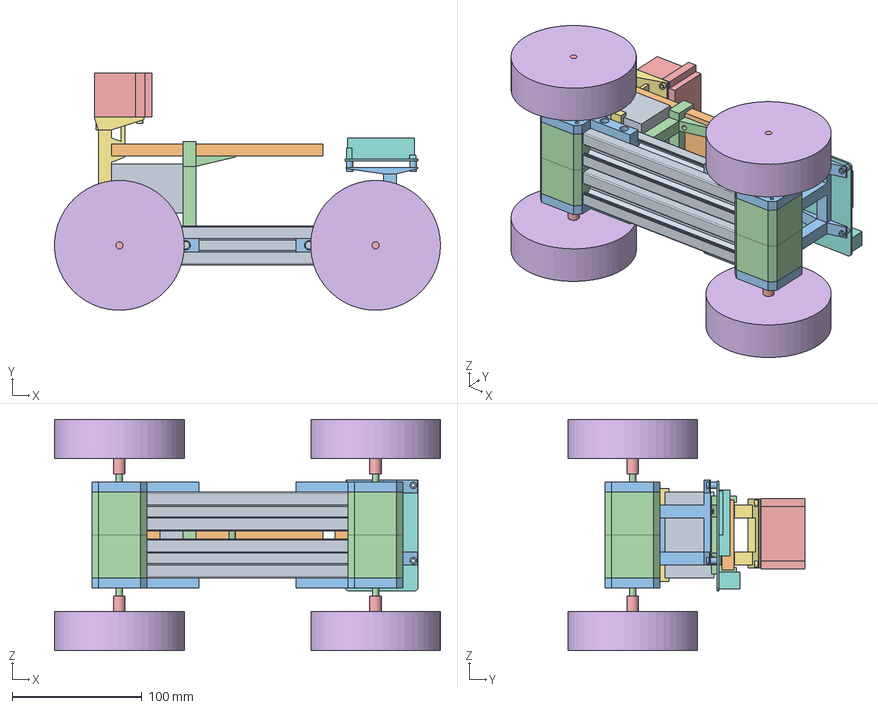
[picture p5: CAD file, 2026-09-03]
docs/cad/full-robot-assembly.stp
297.3 x 182.8 x 178.0 mm
3030-155mm x 2
extrusion-spacers-6mm x 2
motorleg-v2 x 4
olimex_motor x 4
wheel_shaft_5_5_to_5_d x 4
100mm_wheels x 4
lidar_mount
rspi5
12V_battery
breadboard
rspi_mount
breadboard_mount
lidar

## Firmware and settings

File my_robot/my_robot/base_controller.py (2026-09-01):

"""ROS 2 cmd_vel controller and open-loop odometry for a four-wheel base."""

import math
import time

from geometry_msgs.msg import TransformStamped, Twist
from my_robot.stepper_hardware import FourWheelHardware
from nav_msgs.msg import Odometry
import rclpy
from rclpy.node import Node
from tf2_ros import TransformBroadcaster


def clamp(value, lower, upper):
    """Constrain a number to the inclusive bounds."""
    return max(lower, min(upper, value))


class BaseController(Node):
    """Convert differential-drive velocity commands into four step rates."""

    def __init__(self):
        super().__init__('base_controller')
        self.declare_parameter('step_pins', [14, 23, 17, 5])
        self.declare_parameter('dir_pins', [15, 24, 27, 6])
        self.declare_parameter('reset_pins', [4, 25, 22, 26])
        self.declare_parameter('sleep_pins', [12, 7, 16, 1])
        self.declare_parameter(
            'direction_inverted', [True, True, False, False]
        )
        self.declare_parameter('left_steps_per_meter', 707.0)
        self.declare_parameter('right_steps_per_meter', 698.9)
        self.declare_parameter('left_turn_steps_per_radian', 170.0)
        self.declare_parameter('right_turn_steps_per_radian', 482.4)
        self.declare_parameter('max_step_rate', 500.0)
        self.declare_parameter('max_step_acceleration', 300.0)
        self.declare_parameter('command_timeout', 0.5)
        self.declare_parameter('publish_odom', True)
        self.declare_parameter('publish_odom_tf', True)
        self.declare_parameter('debug_logging', False)

        step_pins = self.get_parameter('step_pins').value
        dir_pins = self.get_parameter('dir_pins').value
        reset_pins = self.get_parameter('reset_pins').value
        sleep_pins = self.get_parameter('sleep_pins').value
        direction_inverted = self.get_parameter('direction_inverted').value
        self._left_steps_per_meter = self.get_parameter(
            'left_steps_per_meter'
        ).value
        self._right_steps_per_meter = self.get_parameter(
            'right_steps_per_meter'
        ).value
        self._left_turn_steps_per_radian = self.get_parameter(
            'left_turn_steps_per_radian'
        ).value
        self._right_turn_steps_per_radian = self.get_parameter(
            'right_turn_steps_per_radian'
        ).value
        self._max_rate = self.get_parameter('max_step_rate').value
        self._max_acceleration = self.get_parameter(
            'max_step_acceleration'
        ).value
        self._timeout = self.get_parameter('command_timeout').value
        self._publish_odom = self.get_parameter('publish_odom').value
        self._publish_odom_tf = self.get_parameter('publish_odom_tf').value
        self._debug_logging = self.get_parameter('debug_logging').value
        if min(
            self._left_steps_per_meter,
            self._right_steps_per_meter,
            self._left_turn_steps_per_radian,
            self._right_turn_steps_per_radian,
        ) <= 0.0:
            raise ValueError(
                'Movement calibration values must be positive'
            )

        self._hardware = FourWheelHardware(
            step_pins,
            dir_pins,
            reset_pins,
            sleep_pins,
            direction_inverted,
            debug_callback=(
                self._hardware_debug if self._debug_logging else None
            ),
        )
        self._target_rates = [0.0] * 4
        self._current_rates = [0.0] * 4
        self._last_command = time.monotonic()
        self._watchdog_active = False
        self._last_update = time.monotonic()
        self._last_counts = self._hardware.step_counts()
        self._x = 0.0
        self._y = 0.0
        self._yaw = 0.0

        self.create_subscription(Twist, 'cmd_vel', self._command_callback, 10)
        self._wheel_odom_publisher = self.create_publisher(
            Odometry, 'wheel/odom', 10
        )
        self._odom_publisher = (
            self.create_publisher(Odometry, 'odom', 10)
            if self._publish_odom else None
        )
        self._tf_broadcaster = TransformBroadcaster(self)
        self.create_timer(0.02, self._control_update)
        self.get_logger().info(
            'Four-wheel GPIO base controller ready; '
            f'STEP={step_pins}, DIR={dir_pins}, RESET={reset_pins}, '
            f'SLEEP={sleep_pins}, inverted={direction_inverted}'
        )

    def _hardware_debug(self, message):
        """Write an enabled motor hardware diagnostic."""
        self.get_logger().info(f'[motor debug] {message}')

    def _command_callback(self, message):
        linear = message.linear.x
        angular = message.angular.z
        turn_steps_per_radian = (
            self._left_turn_steps_per_radian
            if angular >= 0.0
            else self._right_turn_steps_per_radian
        )
        left_rate = clamp(
            linear * self._left_steps_per_meter
            - angular * turn_steps_per_radian,
            -self._max_rate,
            self._max_rate,
        )
        right_rate = clamp(
            linear * self._right_steps_per_meter
            + angular * turn_steps_per_radian,
            -self._max_rate,
            self._max_rate,
        )
        self._target_rates = [left_rate, left_rate, right_rate, right_rate]
        self._last_command = time.monotonic()
        self._watchdog_active = False
        if self._debug_logging:
            self.get_logger().info(
                '[motor debug] '
                f'cmd_vel linear={linear:.3f} m/s angular={angular:.3f} rad/s; '
                f'target steps/s left={left_rate:.1f}, right={right_rate:.1f}',
                throttle_duration_sec=0.5,
            )

    def _control_update(self):
        now_monotonic = time.monotonic()
        elapsed = max(now_monotonic - self._last_update, 1e-6)
        self._last_update = now_monotonic
        if now_monotonic - self._last_command > self._timeout:
            self._target_rates = [0.0] * 4
            if not self._watchdog_active:
                self._watchdog_active = True
                if self._debug_logging:
                    self.get_logger().info(
                        '[motor debug] command watchdog expired; stopping'
                    )

        max_change = self._max_acceleration * elapsed
        self._current_rates = [
            current + clamp(target - current, -max_change, max_change)
            for current, target in zip(self._current_rates, self._target_rates)
        ]
        self._hardware.set_rates(self._current_rates)
        deltas = self._publish_odometry(elapsed)
        if self._debug_logging and (
            any(abs(rate) >= 0.01 for rate in self._current_rates)
            or any(deltas)
        ):
            rates = ', '.join(f'{rate:.1f}' for rate in self._current_rates)
            self.get_logger().info(
                '[motor debug] '
                f'actual rates LF/LR/RF/RR=[{rates}] steps/s; '
                f'pulses this cycle={deltas}',
                throttle_duration_sec=1.0,
            )

    def _publish_odometry(self, elapsed):
        counts = self._hardware.step_counts()
        deltas = [
            count - previous
            for count, previous in zip(counts, self._last_counts)
        ]
        self._last_counts = counts
        left_steps = 0.5 * (deltas[0] + deltas[1])
        right_steps = 0.5 * (deltas[2] + deltas[3])
        translation_denominator = (
            self._left_steps_per_meter + self._right_steps_per_meter
        )
        distance = (
            left_steps + right_steps
        ) / translation_denominator
        yaw_numerator = (
            self._left_steps_per_meter * right_steps
            - self._right_steps_per_meter * left_steps
        )
        turn_steps_per_radian = (
            self._left_turn_steps_per_radian
            if yaw_numerator >= 0.0
            else self._right_turn_steps_per_radian
        )
        yaw_change = yaw_numerator / (
            turn_steps_per_radian * translation_denominator
        )
        self._x += distance * math.cos(self._yaw + yaw_change / 2.0)
        self._y += distance * math.sin(self._yaw + yaw_change / 2.0)
        self._yaw += yaw_change
        linear_velocity = distance / elapsed
        angular_velocity = yaw_change / elapsed
        half_yaw = self._yaw / 2.0

        stamp = self.get_clock().now().to_msg()
        odometry = Odometry()
        odometry.header.stamp = stamp
        odometry.header.frame_id = 'odom'
        odometry.child_frame_id = 'base_footprint'
        odometry.pose.pose.position.x = self._x
        odometry.pose.pose.position.y = self._y
        odometry.pose.pose.orientation.z = math.sin(half_yaw)
        odometry.pose.pose.orientation.w = math.cos(half_yaw)
        odometry.twist.twist.linear.x = linear_velocity
        odometry.twist.twist.angular.z = angular_velocity
        odometry.pose.covariance[0] = 0.05
        odometry.pose.covariance[7] = 0.05
        odometry.pose.covariance[35] = 0.10
        self._wheel_odom_publisher.publish(odometry)
        if self._odom_publisher is not None:
            self._odom_publisher.publish(odometry)

        if self._publish_odom_tf:
            transform = TransformStamped()
            transform.header.stamp = stamp
            transform.header.frame_id = 'odom'
            transform.child_frame_id = 'base_footprint'
            transform.transform.translation.x = self._x
            transform.transform.translation.y = self._y
            transform.transform.rotation.z = math.sin(half_yaw)
            transform.transform.rotation.w = math.cos(half_yaw)
            self._tf_broadcaster.sendTransform(transform)
        return deltas

    def destroy_node(self):
        """Disable the motor drivers before destroying the ROS node."""
        self._hardware.close()
        return super().destroy_node()


def main(args=None):
    """Run the base controller node."""
    rclpy.init(args=args)
    node = None
    try:
        node = BaseController()
        rclpy.spin(node)
    except KeyboardInterrupt:
        pass
    finally:
        if node is not None:
            node.destroy_node()
        rclpy.try_shutdown()


if __name__ == '__main__':
    main()

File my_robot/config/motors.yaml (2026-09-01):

base_controller:
  ros__parameters:
    # Order: left-front, left-rear, right-front, right-rear (BCM numbering).
    step_pins: [14, 23, 17, 5]
    dir_pins: [15, 24, 27, 6]
    reset_pins: [4, 25, 22, 26]
    sleep_pins: [12, 7, 16, 1]
    direction_inverted: [true, true, false, false]

    # Directly calibrated physical movement conversions.
    # Original theoretical values: left=650.0, right=650.0, turns=53.6.
    left_steps_per_meter: 707.0
    right_steps_per_meter: 698.9
    # First 90-degree corrections: left=120.6, right=482.4.
    # Left=120.6 produced 80 degrees; corrected by 90/80.
    left_turn_steps_per_radian: 170.0
    right_turn_steps_per_radian: 482.4

    # Pulse frequency controls speed; 200 steps/s allows approximately
    # 0.31 m/s with the calibrated steps-per-metre values.
    # Original conservative limits: rate=75.0, acceleration=100.0.
    max_step_rate: 500.0
    max_step_acceleration: 300.0
    command_timeout: 0.5
    debug_logging: false

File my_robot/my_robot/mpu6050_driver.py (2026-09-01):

"""ROS 2 I2C driver for an MPU6050 accelerometer and gyroscope."""

import math
import struct
import time

import rclpy
from rclpy.node import Node
from sensor_msgs.msg import Imu

try:
    from smbus2 import SMBus
except ImportError:
    SMBus = None


GRAVITY = 9.80665
DEGREES_TO_RADIANS = math.pi / 180.0


class Mpu6050Driver(Node):
    """Read an MPU6050 over I2C and publish standard ROS messages."""

    POWER_MANAGEMENT_1 = 0x6B
    SAMPLE_RATE_DIVIDER = 0x19
    CONFIGURATION = 0x1A
    GYROSCOPE_CONFIG = 0x1B
    ACCELEROMETER_CONFIG = 0x1C
    DATA_START = 0x3B
    WHO_AM_I = 0x75

    def __init__(self):
        super().__init__('mpu6050_driver')
        self.declare_parameter('i2c_bus', 1)
        self.declare_parameter('i2c_address', 0x68)
        self.declare_parameter('frame_id', 'imu_link')
        self.declare_parameter('publish_rate', 100.0)
        self.declare_parameter('calibration_samples', 500)
        self.declare_parameter('gyro_stddev', 0.02)
        self.declare_parameter('accel_stddev', 0.20)
        self.declare_parameter('debug_logging', False)

        if SMBus is None:
            raise RuntimeError(
                'smbus2 is not installed; run: sudo apt install python3-smbus2'
            )

        self._address = self.get_parameter('i2c_address').value
        self._frame_id = self.get_parameter('frame_id').value
        self._debug_logging = self.get_parameter('debug_logging').value
        publish_rate = self.get_parameter('publish_rate').value
        if publish_rate <= 0.0:
            raise ValueError('publish_rate must be positive')

        bus_number = self.get_parameter('i2c_bus').value
        self._bus = SMBus(bus_number)
        if self._debug_logging:
            self.get_logger().info(
                f'[imu debug] opened I2C bus {bus_number}; '
                f'probing address 0x{self._address:02x}'
            )
        try:
            self._initialize_sensor()
        except Exception as error:
            self.get_logger().error(
                f'MPU6050 connection failed on I2C bus {bus_number}, '
                f'address 0x{self._address:02x}: {error}'
            )
            self._bus.close()
            raise
        self._gyro_bias = self._calibrate_gyroscope(
            self.get_parameter('calibration_samples').value
        )
        if self._debug_logging:
            self.get_logger().info(
                '[imu debug] raw gyro bias '
                f'x={self._gyro_bias[0]:.1f}, y={self._gyro_bias[1]:.1f}, '
                f'z={self._gyro_bias[2]:.1f}'
            )

        self._imu_publisher = self.create_publisher(Imu, 'imu/data', 10)
        self.create_timer(1.0 / publish_rate, self._publish_measurement)
        self.get_logger().info(
            f'MPU6050 ready on I2C bus {bus_number}, '
            f'address 0x{self._address:02x}'
        )

    def _initialize_sensor(self):
        self._bus.write_byte_data(
            self._address, self.POWER_MANAGEMENT_1, 0x01
        )
        time.sleep(0.1)
        identity = self._bus.read_byte_data(self._address, self.WHO_AM_I)
        if identity not in (0x68, 0x69):
            raise RuntimeError(
                f'Unexpected MPU6050 identity 0x{identity:02x}'
            )
        if self._debug_logging:
            self.get_logger().info(
                f'[imu debug] connection verified; '
                f'WHO_AM_I returned 0x{identity:02x}'
            )

        # 200 Hz internal sample rate, 44 Hz digital low-pass filter,
        # +/-250 deg/s gyroscope range, and +/-2 g accelerometer range.
        self._bus.write_byte_data(
            self._address, self.SAMPLE_RATE_DIVIDER, 0x04
        )
        self._bus.write_byte_data(
            self._address, self.CONFIGURATION, 0x03
        )
        self._bus.write_byte_data(
            self._address, self.GYROSCOPE_CONFIG, 0x00
        )
        self._bus.write_byte_data(
            self._address, self.ACCELEROMETER_CONFIG, 0x00
        )

    def _read_raw(self):
        block = self._bus.read_i2c_block_data(
            self._address, self.DATA_START, 14
        )
        return struct.unpack('>hhhhhhh', bytes(block))

    def _calibrate_gyroscope(self, sample_count):
        if sample_count <= 0:
            return (0.0, 0.0, 0.0)
        self.get_logger().info(
            f'Calibrating gyro with {sample_count} samples; keep robot still'
        )
        sums = [0.0, 0.0, 0.0]
        for _ in range(sample_count):
            _, _, _, _, gyro_x, gyro_y, gyro_z = self._read_raw()
            sums[0] += gyro_x
            sums[1] += gyro_y
            sums[2] += gyro_z
            time.sleep(0.005)
        return tuple(total / sample_count for total in sums)

    def _publish_measurement(self):
        try:
            accel_x, accel_y, accel_z, _, gyro_x, gyro_y, gyro_z = (
                self._read_raw()
            )
        except OSError as error:
            self.get_logger().error(
                f'MPU6050 I2C read failed: {error}',
                throttle_duration_sec=2.0,
            )
            return

        gyro_scale = DEGREES_TO_RADIANS / 131.0
        accel_scale = GRAVITY / 16384.0
        angular_velocity = [
            (raw - bias) * gyro_scale
            for raw, bias in zip(
                (gyro_x, gyro_y, gyro_z), self._gyro_bias
            )
        ]
        linear_acceleration = [
            raw * accel_scale for raw in (accel_x, accel_y, accel_z)
        ]
        stamp = self.get_clock().now().to_msg()

        message = Imu()
        message.header.stamp = stamp
        message.header.frame_id = self._frame_id
        message.orientation_covariance[0] = -1.0
        (
            message.angular_velocity.x,
            message.angular_velocity.y,
            message.angular_velocity.z,
        ) = angular_velocity
        (
            message.linear_acceleration.x,
            message.linear_acceleration.y,
            message.linear_acceleration.z,
        ) = linear_acceleration
        gyro_variance = self.get_parameter('gyro_stddev').value ** 2
        accel_variance = self.get_parameter('accel_stddev').value ** 2
        for index in (0, 4, 8):
            message.angular_velocity_covariance[index] = gyro_variance
            message.linear_acceleration_covariance[index] = accel_variance
        self._imu_publisher.publish(message)
        if self._debug_logging:
            self.get_logger().info(
                '[imu debug] '
                f'accel=({linear_acceleration[0]:.2f}, '
                f'{linear_acceleration[1]:.2f}, '
                f'{linear_acceleration[2]:.2f}) m/s^2, '
                f'gyro=({angular_velocity[0]:.3f}, '
                f'{angular_velocity[1]:.3f}, '
                f'{angular_velocity[2]:.3f}) rad/s',
                throttle_duration_sec=1.0,
            )
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

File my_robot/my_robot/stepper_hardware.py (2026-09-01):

"""GPIO step/direction output for four independent stepper drivers."""

import threading
import time

try:
    from gpiozero import DigitalOutputDevice
except ImportError:
    DigitalOutputDevice = None


class StepperWheel:
    """Generate pulses for one STEP/DIR/RESET/SLEEP stepper driver."""

    def __init__(
        self,
        step_pin,
        dir_pin,
        reset_pin,
        sleep_pin,
        direction_inverted=False,
        wheel_name='wheel',
        debug_callback=None,
    ):
        if DigitalOutputDevice is None:
            raise RuntimeError(
                'gpiozero is not installed; run: '
                'sudo apt install python3-gpiozero'
            )

        self._step = DigitalOutputDevice(step_pin, initial_value=False)
        self._direction = DigitalOutputDevice(dir_pin, initial_value=False)
        self._reset = DigitalOutputDevice(reset_pin, initial_value=False)
        self._sleep = DigitalOutputDevice(sleep_pin, initial_value=False)
        self._inverted = direction_inverted
        self._wheel_name = wheel_name
        self._debug_callback = debug_callback
        self._rate = 0.0
        self._step_count = 0
        self._awake = False
        self._lock = threading.Lock()
        self._changed = threading.Event()
        self._stopping = threading.Event()
        self._thread = threading.Thread(target=self._pulse_loop, daemon=True)
        # RESET and SLEEP are active-low on A4988-style drivers. Perform one
        # startup reset while the driver is asleep, then leave RESET inactive.
        time.sleep(0.00001)
        self._reset.on()
        self._debug('startup reset complete; driver sleeping')
        self._thread.start()

    def _debug(self, message):
        if self._debug_callback is not None:
            self._debug_callback(f'{self._wheel_name}: {message}')

    def set_rate(self, signed_steps_per_second):
        """Set the logical pulse rate and direction."""
        new_rate = float(signed_steps_per_second)
        with self._lock:
            rate_changed = new_rate != self._rate
            self._rate = new_rate
        if rate_changed:
            self._changed.set()

    def step_count(self):
        """Return the signed count of pulses generated."""
        with self._lock:
            return self._step_count

    def _pulse_loop(self):
        last_sign = 0
        while not self._stopping.is_set():
            with self._lock:
                rate = self._rate
                self._changed.clear()

            if abs(rate) < 0.01:
                self._step.off()
                if self._awake:
                    self._sleep.off()
                    self._awake = False
                    self._debug('SLEEP low; driver disabled')
                self._changed.wait(timeout=0.1)
                last_sign = 0
                continue

            if not self._awake:
                self._sleep.on()
                # A4988-style drivers need at least 1 ms from wake to STEP.
                time.sleep(0.001)
                self._awake = True
                self._debug('SLEEP high; driver awake')

            logical_sign = 1 if rate > 0.0 else -1
            if logical_sign != last_sign:
                self._step.off()
                physical_forward = (logical_sign > 0) != self._inverted
                self._direction.value = physical_forward
                time.sleep(0.00001)
                last_sign = logical_sign

            half_period = 0.5 / abs(rate)
            self._step.on()
            rate_changed = self._changed.wait(timeout=half_period)
            self._step.off()
            with self._lock:
                self._step_count += logical_sign
            if not rate_changed:
                self._changed.wait(timeout=half_period)

    def close(self):
        """Stop pulses, put the driver to sleep, and release GPIO."""
        self.set_rate(0.0)
        self._stopping.set()
        self._changed.set()
        self._thread.join(timeout=1.0)
        self._step.off()
        self._sleep.off()
        self._step.close()
        self._direction.close()
        self._sleep.close()
        self._reset.close()


class FourWheelHardware:
    """Own and update the four GPIO wheel channels."""

    def __init__(
        self,
        step_pins,
        dir_pins,
        reset_pins,
        sleep_pins,
        direction_inverted,
        debug_callback=None,
    ):
        values = (
            step_pins,
            dir_pins,
            reset_pins,
            sleep_pins,
            direction_inverted,
        )
        if any(len(value) != 4 for value in values):
            raise ValueError(
                'Each wheel parameter must contain exactly four values'
            )
        wheel_names = ('LF', 'LR', 'RF', 'RR')
        self.wheels = []
        for name, step, direction, reset, sleep, inverted in zip(
            wheel_names, *values
        ):
            wheel = StepperWheel(
                step,
                direction,
                reset,
                sleep,
                inverted,
                wheel_name=name,
                debug_callback=debug_callback,
            )
            self.wheels.append(wheel)
        if debug_callback is not None:
            debug_callback(
                'GPIO connection initialized for wheels LF, LR, RF, RR'
            )

    def set_rates(self, rates):
        """Set logical rates in LF, LR, RF, RR order."""
        for wheel, rate in zip(self.wheels, rates):
            wheel.set_rate(rate)

    def step_counts(self):
        """Return signed pulse counts in LF, LR, RF, RR order."""
        return [wheel.step_count() for wheel in self.wheels]

    def close(self):
        """Disable and release all wheel channels."""
        for wheel in self.wheels:
            wheel.close()

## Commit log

2026-06-23 lidar testing
2026-08-25 chat starter
    [motors.yaml, robot.urdf]
2026-08-25 debugged and set up
    [motors.yaml]
2026-08-31 steps per meter fix
    [motors.yaml]
2026-09-01 Record physical bring-up fixes for calibration, IMU load, and Nav2.
    Floor tests needed directional turn coefficients, lighter mapping CPU, and a cmd_vel_smoothed remap so Nav2 commands reach the motors.
    [motors.yaml]
2026-09-01 Fix Gazebo skid-steer turning and Nav2 command routing so simulated mapping and navigation work.
    Wheel friction and Jazzy cmd_vel_smoothed remapping were blocking real motion; AMCL now seeds in sim and RViz loads the map automatically.
    [test_room.sdf]
2026-09-01 Remove unused Nav2 and motor-driver leftovers so declared dependencies match the launched stack.
    [motors.yaml]
2026-09-01 Drop unused IMU temperature output and restore motor calibration history comments.
    [motors.yaml]
2026-09-03 Document the robot as a project: goal, hardware, CAD, issues, and worklog.
    Reorganize the README around bring-up history from the project notebook, and add the Fusion STEP assembly plus notebook figures.
    [full-robot-assembly.stp]
